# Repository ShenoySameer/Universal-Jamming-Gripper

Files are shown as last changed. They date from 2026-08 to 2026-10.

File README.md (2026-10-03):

# Universal-Jamming-Gripper
A custom modeled, 3D-printed 4-axis robotic arm with a pneumatic universal jamming gripper. Controlled using an ESP32 micro-controller and any generic video game controller, this project combines mechanical design, power electronics, embedded control, and soft robotics to adaptively pick and place irregular objects.

To access the full DEMO: https://drive.google.com/file/d/1VVH4_Hc1vpUiFQFAnJGJaWFHKPsOv7K6/view?usp=drive_link

Jamming-Gripper-Demo

## Components & Specifications

| Subsystem | Component | Specifications & Engineering Function |
| --- | --- | --- |
| **Microcontroller** | ESP-WROOM-32 | Central controller, I2C communication, and GPIO triggers. |
| **PWM Driver** | PCA9685 Module | 16-Channel 12-bit PWM expansion board driving joint servos over I2C. |
| **Joint Actuators** | 40KG Digital Servos | High-torque metal-gear servos providing 4 degrees of freedom. |
| **Mechanical Bearings** | AXK5578 Thrust Bearings | Needle roller bearings absorbing axial loads at primary joint linkages. |
| **Pneumatic Vacuum** | VN-T1 Micro Diaphragm Pump | 12V DC vacuum pump used to suck air from the gripper chamber. |
| **Pneumatic Control** | 2-Way Solenoid Valve | 12V DC valve used to vent atmospheric pressure into the membrane for release. |
| **Isolation Circuit** | Optocoupler Relay Modules | Optically isolates 5V micro-controller logic from 12V inductive switching noise. |
| **Power Supply 1** | 5V 10A DC Power Adapter | High-amperage dedicated power rail for the PCA9685 and joint servos. |
| **Power Supply 2** | 12V DC Power Adapter | Dedicated supply for high-current pneumatic pump and solenoid actuation. |
| **Teleoperation Input** | Nintendo Switch Controller | Wired input controller mapped for real-time Cartesian/joint control. |
| **Fasteners** | M3 Hardware + Brass Inserts | Socket-head machine screws paired with thermal heat-set brass inserts. |
| **Latex Membrane** | Basic party balloon | filled with coffee grounds to act as the gripper |

---
<p align="center">
Robot_Arm_Collapse_GIF
</p>

## System Architecture

```text
                        ┌──────────────────────────────┐
                        │ Nintendo Switch Controller   │
                        └──────────────┬───────────────┘
                                       │
                                       ▼ 
                        ┌──────────────────────────────┐
                        │      ESP32 Controller        │
                        └──────┬────────────────┬──────┘
                               │                │
                    (I2C Line) │                │ (GPIO Signals)
                               ▼                ▼
┌────────────────────────────────────────┐   ┌────────────────────────────────────────┐
│      PCA9685 12-Bit PWM Driver         │   │       Optocoupler Relay Modules        │
└──────────────────┬─────────────────────┘   └──────────────────┬─────────────────────┘
                   │                                            │
   (5V 10A Rail)   │                               (12V Rail)   │
                   ▼                                            ▼
┌────────────────────────────────────────┐   ┌────────────────────────────────────────┐
│    4x 40KG High-Torque Joint Servos    │   │      12V Vacuum Pump & Solenoid        │
└────────────────────────────────────────┘   └──────────────────┬─────────────────────┘
                                                                │ (Air Tubing)
                                                                ▼
                                             ┌────────────────────────────────────────┐
                                             │      Universal Jamming Gripper         │
                                             └────────────────────────────────────────┘

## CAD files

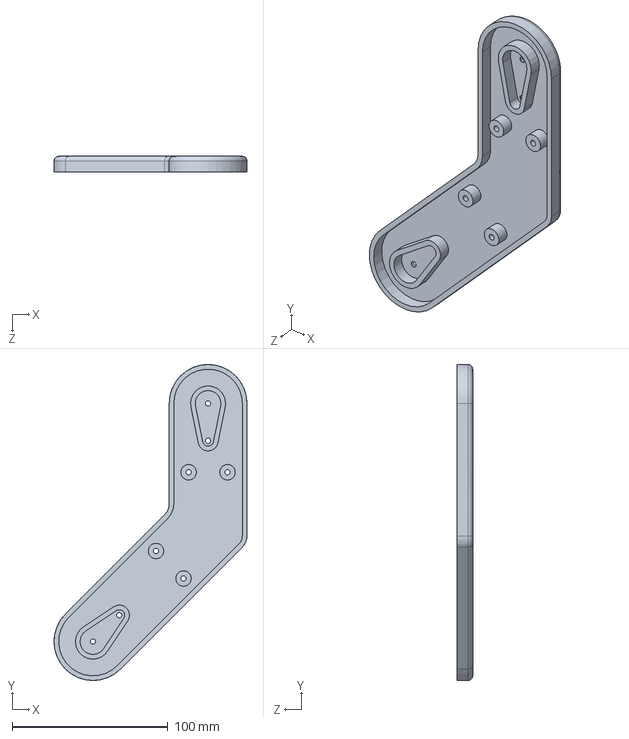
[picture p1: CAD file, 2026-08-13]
SolidWorks-Files/RA_Lever_Upper_Arm.SLDPRT
124.0 x 203.1 x 10.0 mm

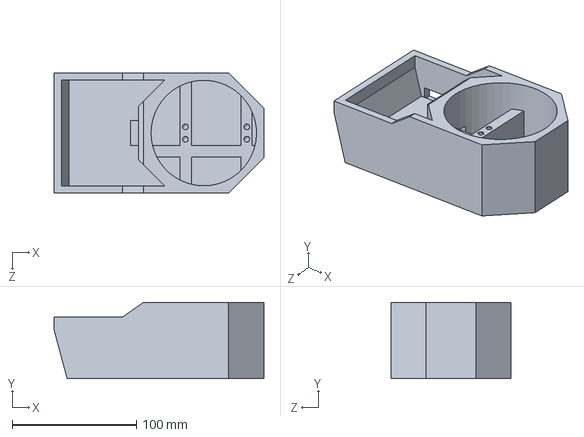
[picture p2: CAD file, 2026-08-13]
SolidWorks-Files/RA_Base.SLDPRT
169.2 x 61.6 x 97.0 mm

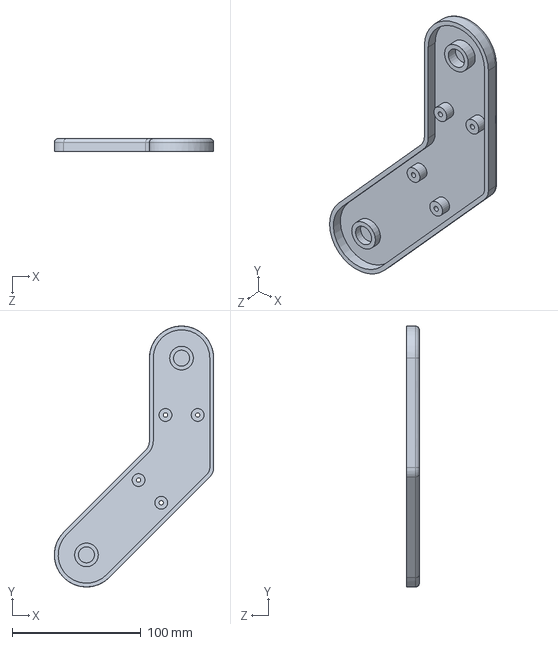
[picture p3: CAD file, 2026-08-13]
SolidWorks-Files/RA_Servo_Upper_Arm.SLDPRT
124.0 x 203.1 x 10.0 mm

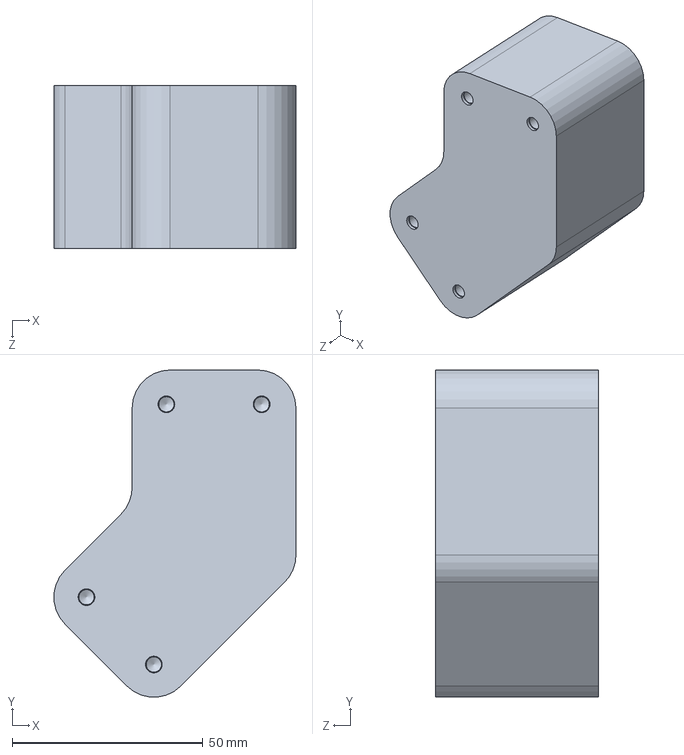
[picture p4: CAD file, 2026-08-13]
SolidWorks-Files/Upper_Arm_sandwhiched_piece.SLDPRT
63.5 x 85.8 x 42.8 mm

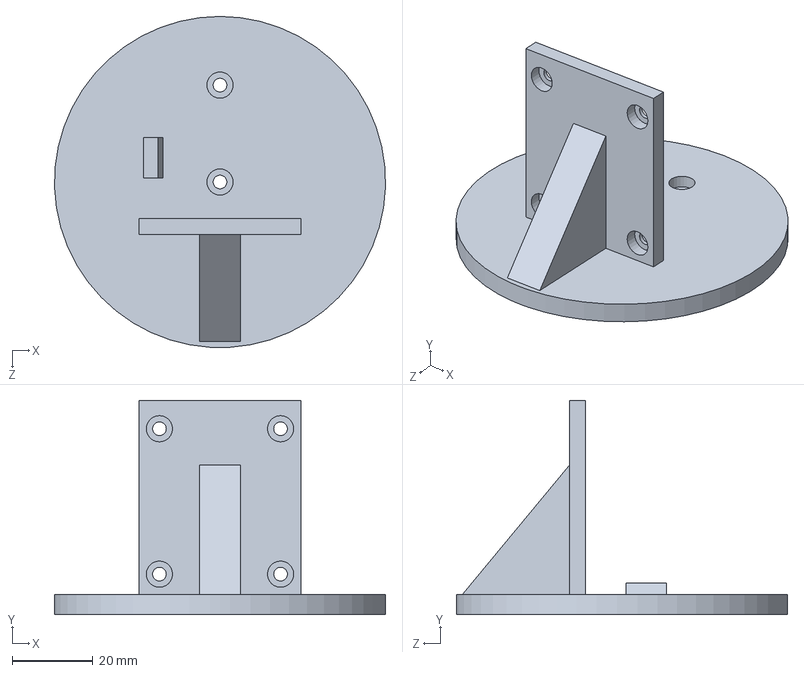
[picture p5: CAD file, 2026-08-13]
SolidWorks-Files/RA_Shoulder_Mount.SLDPRT
82.0 x 53.0 x 82.0 mm

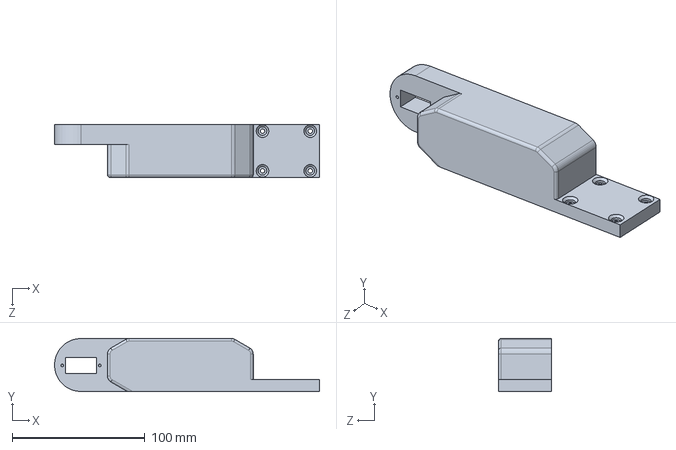
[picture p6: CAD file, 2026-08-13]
SolidWorks-Files/RA_Forearm.SLDPRT
200.0 x 40.0 x 40.0 mm

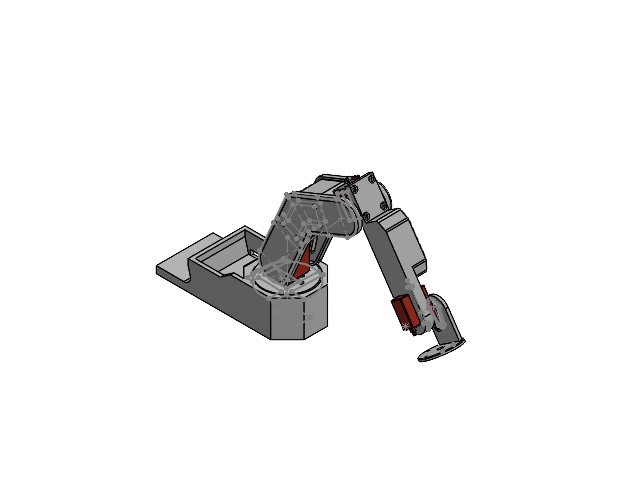
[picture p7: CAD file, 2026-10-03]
SolidWorks-Files/Robot_Arm Assembly.SLDASM
RA_Base
RA_Shoulder_Mount
RA_Upper_Arm
Upper_Arm_sandwhiched_piece
RA_Forearm
Bearing_Spacer
Gripper_top
MirrorRA_Upper_Arm - Copy

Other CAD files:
SolidWorks-Files/servo_mount_shaft1.SLDPRT
SolidWorks-Files/servo_mount_case.SLDPRT

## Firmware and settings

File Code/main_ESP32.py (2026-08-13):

import sys
import select
import time
from machine import I2C, Pin

# RELAY SETUP
pump_relay = Pin(26, Pin.OUT)
valve_relay = Pin(27, Pin.OUT)
pump_relay.value(0)
valve_relay.value(0)

# PCA9685 SETUP
# 1. Connect to the PCA9685 over I2C
i2c = I2C(0, scl=Pin(22), sda=Pin(21), freq=100000)
address = 0x40

# 2. Configure the PCA9685 hardware to 50Hz
i2c.writeto_mem(address, 0x00, b'\x10')
time.sleep_ms(5)
i2c.writeto_mem(address, 0xFE, b'\x79')
i2c.writeto_mem(address, 0x00, b'\xa1')
time.sleep_ms(5)

# 3. Helper function to move the servo
def move_servo(channel, tick_value):
    register = 0x06 + (channel * 4)
    data = bytearray([0, 0, tick_value & 0xFF, tick_value >> 8])
    i2c.writeto_mem(address, register, data)

# 4. Set up a non-blocking listener for the USB cable
poll_obj = select.poll()
poll_obj.register(sys.stdin, select.POLLIN)
buffer = ""

while True:
    # Check if PyCharm has sent text down the USB cable
    poll_results = poll_obj.poll(0)
    if poll_results:
        # Read exactly one character at a time
        char = sys.stdin.read(1)

        # When PyCharm sends a newline ('\n'), the command is complete
        if char == '\n':
            try:
                # Check for pump or valve commands
                if buffer.startswith("PUMP"):
                    parts = buffer.split(',')
                    state = int(parts[1])
                    pump_relay.value(state)
                    print(f"Pump set to {state}")
                elif buffer.startswith("VALVE"):
                    parts = buffer.split(',')
                    state = int(parts[1])
                    valve_relay.value(state)
                    print(f"Valve set to {state}")
                else:
                    # Otherwise, treat it as a servo command
                    parts = buffer.split(',')
                    if len(parts) == 2:
                        channel = int(parts[0])
                        position = int(parts[1])
                        move_servo(channel, position)
            except Exception as e:
                print(f"Error processing command: {e}")

            # Clear the buffer for the next incoming command
            buffer = ""
        else:
            buffer += char

    # Delay to prevent the ESP32 from freezing
    time.sleep(0.01)

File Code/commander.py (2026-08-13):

import serial
import time
import pygame

# Connect to the ESP32
COM_PORT = 'COM7'
BAUD_RATE = 115200

print(f"Connecting to ESP32 on {COM_PORT}...")
try:
    esp32 = serial.Serial(COM_PORT, BAUD_RATE, timeout=0.1)
    esp32.setDTR(False)
    esp32.setRTS(False)
    time.sleep(2)
    print("Connected successfully!")
except Exception as e:
    print(f"Failed to connect: {e}")
    exit()

# Robot Arm Configuration
SAFE_MIN = 50
SAFE_MAX = 450

# WIRING CONFIGURATION
CH_0 = 0
CH_A = 1
CH_E = 2
CH_4 = 4

# Starting Positions
ch0_pos = 303.0
chA_pos = 311.0
chE_pos = 290.0
ch4_pos = 250.0

# Speed multiplier
SPEED = 6.0

def send_command(channel, position):
    command_text = f"{channel},{int(position)}\n"
    esp32.write(command_text.encode('utf-8'))

def stop_and_release():
    """Turn pump off and open valve so the gripper vents back to room pressure."""
    esp32.write(b"PUMP,0\n")
    esp32.write(b"VALVE,1\n")
    time.sleep(0.1)

# Setup Pygame & USB Controller
pygame.init()
pygame.joystick.init()
screen = pygame.display.set_mode((300, 200))
pygame.display.set_caption("Direct Robot Commander")

if pygame.joystick.get_count() == 0:
    print("ERROR: No USB controller found! Please plug it in.")
    exit()

controller = pygame.joystick.Joystick(0)
controller.init()
print(f"Connected to Gamepad: {controller.get_name()}")
print("Left Stick L/R: Channel 0")
print("Left Stick U/D: Channel A")
print("Right Stick U/D: Channel E")
print("Press 'A'/'Cross' to GRAB, 'X'/'Square' to RELEASE")
print("Press 'B' or 'Circle' to quit (auto-releases first).")

# Wake up and center the robot
send_command(CH_0, ch0_pos)
send_command(CH_A, chA_pos)
send_command(CH_E, chE_pos)
send_command(CH_4, ch4_pos)
time.sleep(1)

# The Main Control Loop
running = True

old_ch0 = int(ch0_pos)
old_chA = int(chA_pos)
old_chE = int(chE_pos)
old_ch4 = int(ch4_pos)

while running:
    # Check ESP32 Serial
    while esp32.in_waiting:
        esp32_message = esp32.readline().decode('utf-8', errors='ignore').strip()
        if esp32_message:
            print(f"ESP32 says: {esp32_message}")

    # Process events
    for event in pygame.event.get():
        if event.type == pygame.QUIT:
            running = False

        elif event.type == pygame.JOYBUTTONDOWN:
            if event.button == 1:  # 'B' or 'Circle' - Quit
                print("Quitting program... releasing and stopping pump first")
                stop_and_release()
                running = False

            elif event.button == 0:  # 'A' or 'Cross' - GRAB
                print("Command: GRAB (Pump ON, valve open)")
                esp32.write(b"PUMP,1\n")
                esp32.write(b"VALVE,1\n")

            elif event.button == 2:  # 'X' or 'Square' - RELEASE
                print("Command: RELEASE (Pump OFF, valve open to vent)")
                stop_and_release()

    # READ CONTROLLER INPUTS

    # 1. Channel 0: Left Stick Left/Right
    stick_lx = controller.get_axis(0)
    if abs(stick_lx) > 0.2:
        ch0_pos += stick_lx * SPEED

    # 2. Channel A: Left Stick Up/Down
    stick_ly = controller.get_axis(1)
    if abs(stick_ly) > 0.2:
        chA_pos += stick_ly * SPEED

    # 3. Channel E: Right Stick Up/Down
    stick_ry = controller.get_axis(3)
    if abs(stick_ry) > 0.2:
        chE_pos -= stick_ry * SPEED

    # APPLY SAFETY CLAMPS
    ch0_pos = max(SAFE_MIN, min(SAFE_MAX, ch0_pos))
    chA_pos = max(SAFE_MIN, min(SAFE_MAX, chA_pos))
    chE_pos = max(SAFE_MIN, min(SAFE_MAX, chE_pos))
    ch4_pos = max(SAFE_MIN, min(SAFE_MAX, ch4_pos))

    # SEND COMMANDS IF MOVED
    cur_ch0 = int(ch0_pos)
    cur_chA = int(chA_pos)
    cur_chE = int(chE_pos)
    cur_ch4 = int(ch4_pos)

    if cur_ch0 != old_ch0:
        send_command(CH_0, cur_ch0)
        old_ch0 = cur_ch0

    if cur_chA != old_chA:
        send_command(CH_A, cur_chA)
        old_chA = cur_chA

    if cur_chE != old_chE:
        send_command(CH_E, cur_chE)
        old_chE = cur_chE

    if cur_ch4 != old_ch4:
        send_command(CH_4, cur_ch4)
        old_ch4 = cur_ch4

    time.sleep(0.08)

stop_and_release()
esp32.close()
pygame.quit()
print("Connection closed.")

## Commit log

2026-08-13 Rename RA_Lever_Upper_Arm.SLDPRT to SolidWorks-Files /RA_Lever_Upper_Arm.SLDPRT
    [RA_Lever_Upper_Arm.SLDPRT]
2026-08-13 Rename RA_Servo_Upper_Arm.SLDPRT to SolidWorks-Files/RA_Servo_Upper_Arm.SLDPRT
    [RA_Servo_Upper_Arm.SLDPRT]
2026-08-13 Rename RA_Shoulder_Mount.SLDPRT to SolidWorks-Files/RA_Shoulder_Mount.SLDPRT
    [RA_Shoulder_Mount.SLDPRT]
2026-08-13 Rename Robot_Arm Assembly.SLDASM to SolidWorks-Files/Robot_Arm Assembly.SLDASM
    [Robot_Arm Assembly.SLDASM]
2026-08-13 Rename Upper_Arm_sandwhiched_piece.SLDPRT to SolidWorks-Files/Upper_Arm_sandwhiched_piece.SLDPRT
    [Upper_Arm_sandwhiched_piece.SLDPRT]
2026-08-13 Rename servo_mount_case.SLDPRT to SolidWorks-Files/servo_mount_case.SLDPRT
    [servo_mount_case.SLDPRT]
2026-08-13 Rename servo_mount_shaft1.SLDPRT to SolidWorks-Files/servo_mount_shaft1.SLDPRT
    [servo_mount_shaft1.SLDPRT]
2026-10-03 Add robot arm collapse image to README
    Added an image of the robot arm collapse to the README.
2026-10-03 Center align the robot arm GIF in README
    Updated image alignment in README.md.
